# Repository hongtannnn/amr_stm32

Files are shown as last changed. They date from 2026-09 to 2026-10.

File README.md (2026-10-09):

# AMR Hardware & PCB Design (amr_stm32)



[]()

A low-level controller board and hardware system designed as the foundation for an Autonomous Mobile Robot (AMR). The project focuses on real-time task processing, sensor communication, and motor control in preparation for future integration with ROS 2, SLAM algorithms, and autonomous navigation.

## 📸 Board Preview

| 3D Render | Bare PCB (Unassembled) | Real Board (Assembled) |
| :---: | :---: | :---: |
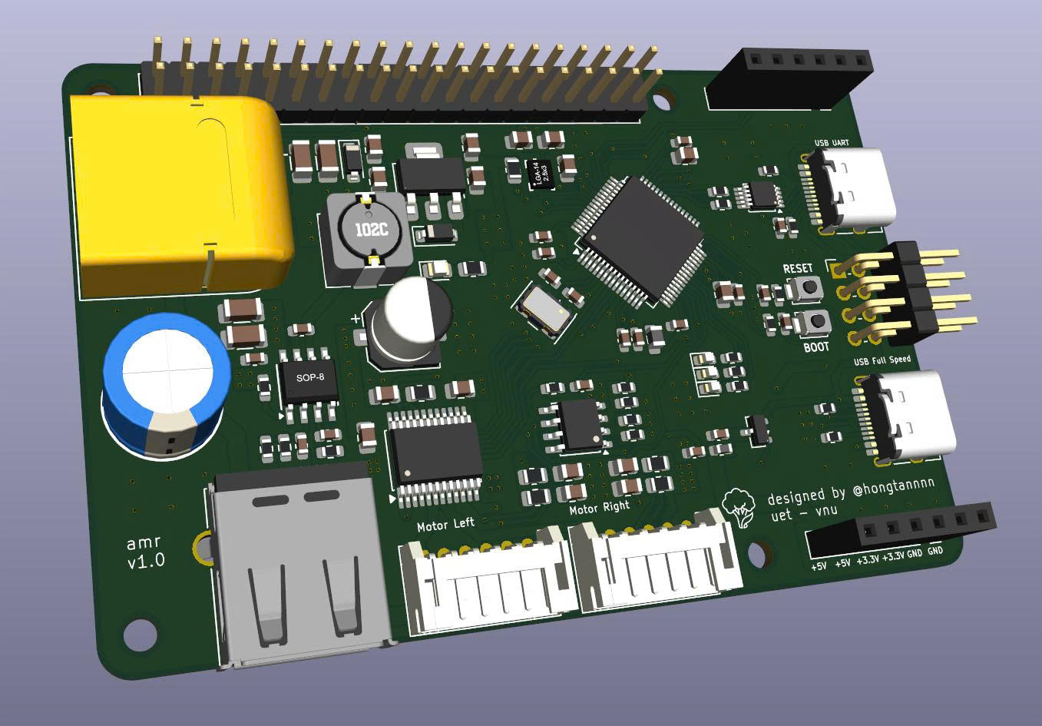
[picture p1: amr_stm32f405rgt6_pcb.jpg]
AMR STM32 3D Render
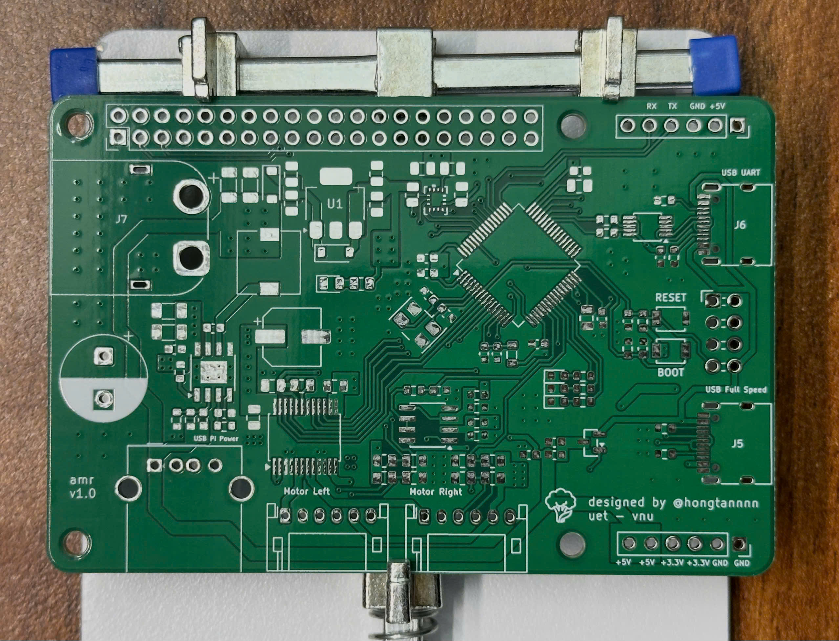
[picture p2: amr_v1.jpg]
AMR STM32 Bare PCB
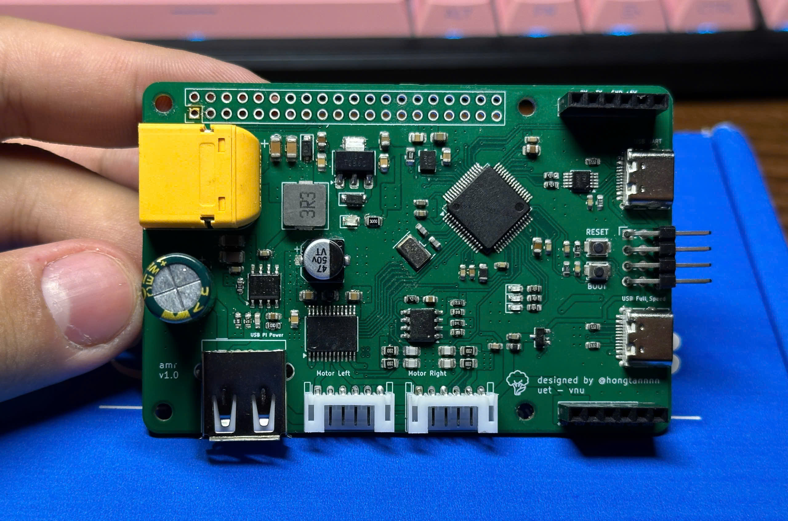
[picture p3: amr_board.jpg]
AMR STM32 Real Board
|  |  |  |
| *Completed PCB design featuring peripheral connectors, power supply block, and central microcontroller.* | *Newly fabricated AMR v1.0 bare board, showing silkscreen details and routing before component assembly.* | *Actual assembled PCB (AMR v1.0) with all components soldered and ready for testing.* |

## 🚀 Hardware Features

-   **Central Microcontroller (MCU):** Utilizes the **STM32F405RGT6** chip, providing powerful processing capabilities for PID algorithms and high-speed encoder reading.
-   **Industrial-grade Design:** 4-layer layout with dedicated GND and Power (VCC) planes, ensuring Signal Integrity and Electromagnetic Interference (EMI) reduction when operating in environments with electrical motors.

## 🛠 Tools & Software

-   **Hardware Design (EDA):** KiCad
-   **Embedded Programming:** STM32CubeIDE / STM32CubeMX
-   **Mechanical Design (CAD):** Autodesk Fusion 360

## 🎯 Future Roadmap

- [ ] Complete basic Firmware: Read encoders, control DC/BLDC motors via PID.
- [ ] Establish stable UART/I2C communication protocols between the STM32 and embedded computers (Raspberry Pi/Mini PC).
- [ ] Integrate the microcontroller package into the **ROS 2** network (using micro-ROS or rosserial).
- [ ] Deploy LiDAR and IMU sensors for mapping (SLAM) and navigation.

---
**Author:** Truong Hong Tan (@hongtannnn)  
*Student at the University of Engineering and Technology (UET) - Vietnam National University, Hanoi.*

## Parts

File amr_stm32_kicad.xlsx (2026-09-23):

Reference | Qty | Value | Footprint
C1,C2 | 2 | 2.2uF | Capacitor_SMD:C_0603_1608Metric
C9 | 1 | 10uF/16V | Capacitor_SMD:C_0805_2012Metric
C10,C11,C15,C17,C19,C20,C49 | 7 | 100nF/50V | Capacitor_SMD:C_0805_2012Metric
C12 | 1 | 22uF/10V | Capacitor_SMD:C_0805_2012Metric
C16 | 1 | 1uF/16V | Capacitor_SMD:C_0805_2012Metric
C18 | 1 | 10uF/25V | Capacitor_SMD:CP_Elec_6.3x7.7 | shopee
C21,C22,C23,C24 | 4 | 20pF/50V | Capacitor_SMD:C_0805_2012Metric
C25,C26,C27,C28,C29,C31,C36,C37,C39,C41,C44 | 9 | 100nF | Capacitor_SMD:C_0603_1608Metric
C30 | 1 | 1uF | Capacitor_SMD:C_0603_1608Metric
C32,C33 | 2 | 2.2uF | Capacitor_SMD:C_0805_2012Metric
C34,C35 | 2 | 22pF | Capacitor_SMD:C_0603_1608Metric
C38, C43 | 1 | 470nF | Capacitor_SMD:C_0603_1608Metric
C40,C47 | 2 | 10uF | Capacitor_SMD:C_1206_3216Metric
C42 | 1 | 5pF | Capacitor_SMD:C_0603_1608Metric
C45,C46 | 2 | 22uF | Capacitor_SMD:C_1206_3216Metric
C48 | 1 | 1000uF/35V | Capacitor_THT:CP_Radial_D10.0mm_P5.00mm
D1,D2 | 2 | D_Schottky 1A/40V | Diode_SMD:D_SOD-123
D3 | 1 | LED | LED_SMD:LED_0805_2012Metric
D5 | 1 | LED_RUN | LED_SMD:LED_0603_1608Metric
D6,D7 | 2 | LED_ERR | LED_SMD:LED_0603_1608Metric
FB1 | 1 | FerriteBead | Inductor_SMD:L_0805_2012Metric
FB2 | 1 | F120R | Inductor_SMD:L_0603_1608Metric
J1 | 1 | Header 2x20 | Connector_PinHeader_2.54mm:PinHeader_2x20_P2.54mm_Vertical
J2 | 1 | Motor_Left | Connector_JST:JST_PH_S6B-PH-K_1x06_P2.00mm_Horizontal
J3 | 1 | Motor_right | Connector_JST:JST_PH_S6B-PH-K_1x06_P2.00mm_Horizontal
J4 | 1 | ST_Link | Connector_PinHeader_2.54mm:PinHeader_2x04_P2.54mm_Horizontal
J5 | 1 | USB_FS_Interface | Connector_USB:USB_C_Receptacle_HRO_TYPE-C-31-M-12
J6 | 1 | USB_UART | Connector_USB:USB_C_Receptacle_HRO_TYPE-C-31-M-12
J7 | 1 | +12V_BAT | Connector_AMASS:AMASS_XT60PW-M_1x02_P7.20mm_Horizontal
J8 | 1 | USB_A_Pi | Connector_USB:USB_A_Molex_67643_Horizontal
J9 | 1 | UART | Connector_PinSocket_2.54mm:PinSocket_1x06_P2.54mm_Vertical
J10 | 1 | VCC | Connector_PinSocket_2.54mm:PinSocket_1x06_P2.54mm_Vertical
L2 | 1 | 3.3uH | Inductor_SMD:L_7.3x7.3_H4.5
Q1 | 1 | FDN304P | Package_TO_SOT_SMD:SOT-23
R3 | 1 | 300Ohm | Resistor_SMD:R_0805_2012Metric
R4,R5,R7,R8,R9,R10 | 6 | 10kOhm | Resistor_SMD:R_0805_2012Metric
R6,R11,R14,R27 | 4 | 10kOhm | Resistor_SMD:R_0603_1608Metric
R12,R13,R21,R22 | 4 | 5.1kOhm | Resistor_SMD:R_0603_1608Metric
R15 | 1 | 2kOhm | Resistor_SMD:R_0603_1608Metric
R16 | 1 | 9kOhm | Resistor_SMD:R_0603_1608Metric
R17 | 1 | 1kOhm | Resistor_SMD:R_0603_1608Metric
R18,R19,R20 | 3 | 470Ohm | Resistor_SMD:R_0603_1608Metric
R23,R24,R29 | 3 | 330 Ohm | Resistor_SMD:R_0603_1608Metric
R25 | 1 | 374kOhm | Resistor_SMD:R_0603_1608Metric
R26 | 1 | 49.9kOhm | Resistor_SMD:R_0603_1608Metric
R28 | 1 | 100kOhm | Resistor_SMD:R_0603_1608Metric
SW1 | 1 | SW_Reset | Button_Switch_SMD:SW_SPST_B3U-1000P
SW2 | 1 | SW_BOOT | Button_Switch_SMD:SW_SPST_B3U-1000P
U2 | 1 | ap2112k-3.3 | Package_TO_SOT_SMD:SOT-23-5
U3 | 1 | BMI323 | BMI323:BMI323_BOS-L
U4 | 1 | TB6612FNG | Package_SO:SSOP-24_5.3x8.2mm_P0.65mm
U5 | 1 | STM32F405RGTx | Package_QFP:LQFP-64_10x10mm_P0.5mm
U6 | 1 | LM358 | Package_SO:SOIC-8_3.9x4.9mm_P1.27mm
U7 | 1 | CH340E | Package_SO:MSOP-10_3x3mm_P0.5mm
U9 | 1 | TPS56528DDA | Package_SO:Texas_HSOP-8-1EP_3.9x4.9mm_P1.27mm_ThermalVias
Y2 | 1 | 8MHz | Crystal:Crystal_SMD_5032-4Pin_5.0x3.2mm

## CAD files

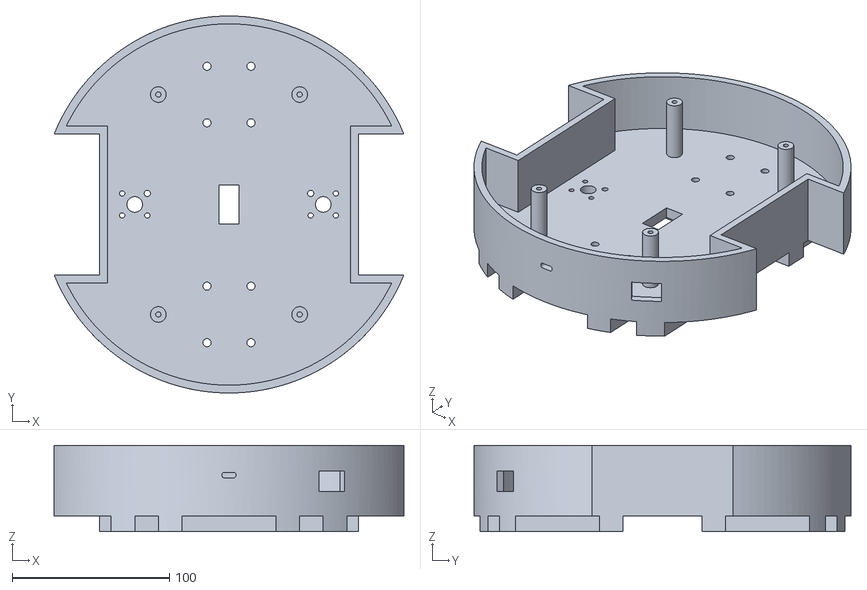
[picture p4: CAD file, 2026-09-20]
AMR_3D/Tang1.stl
222.5 x 240.0 x 55.0

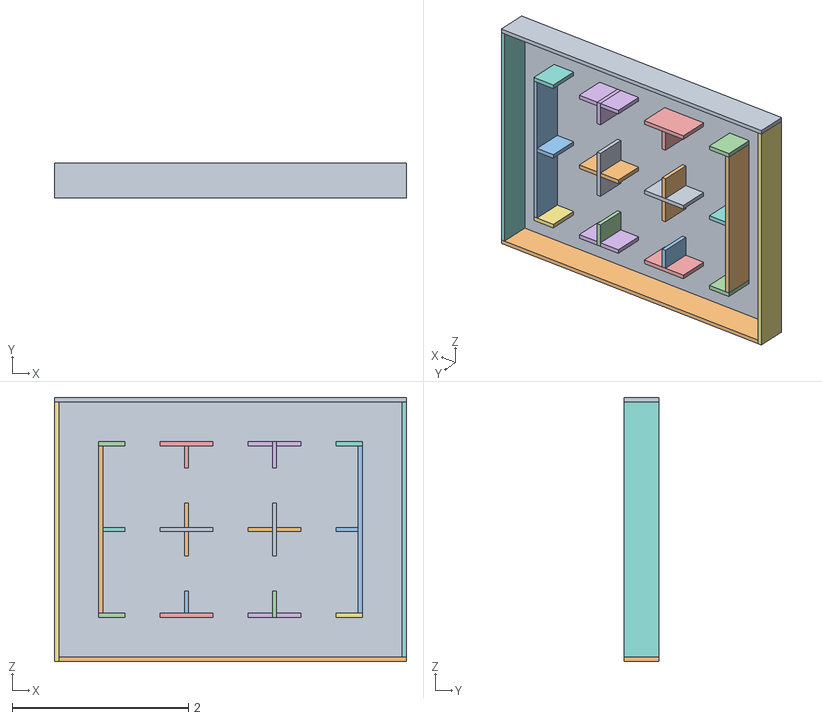
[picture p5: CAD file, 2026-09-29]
gazebo/maze_map.obj
4.00 x 0.4 x 3.00
Plane

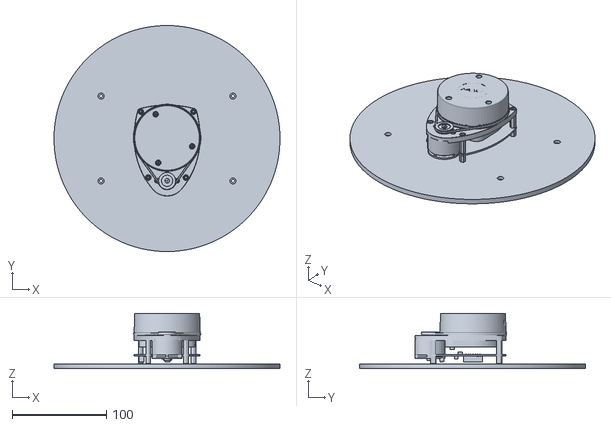
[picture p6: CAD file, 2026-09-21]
urdf/robot_assembly_description/meshes/Tang3_24cm_ComponentLidar_1_1.stl
240.0 x 240.0 x 58.7

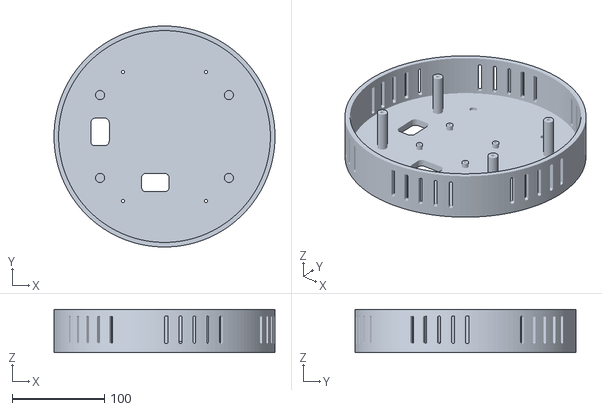
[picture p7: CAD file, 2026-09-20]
AMR_3D/Tang2.stl
240.0 x 240.0 x 47.0

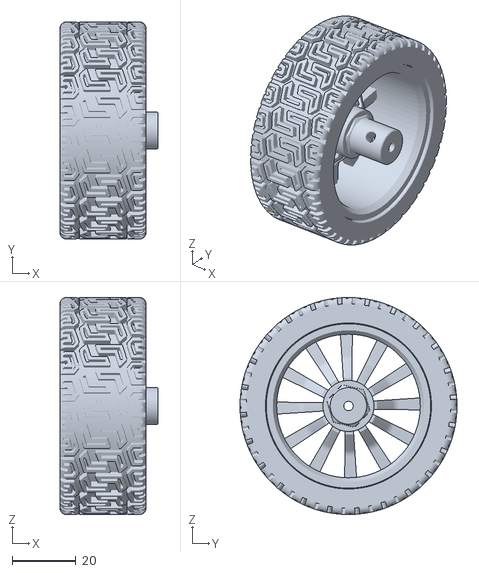
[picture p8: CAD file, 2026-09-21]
urdf/robot_assembly_description/meshes/left_wheel_1_1.stl
30.7 x 68.0 x 68.0

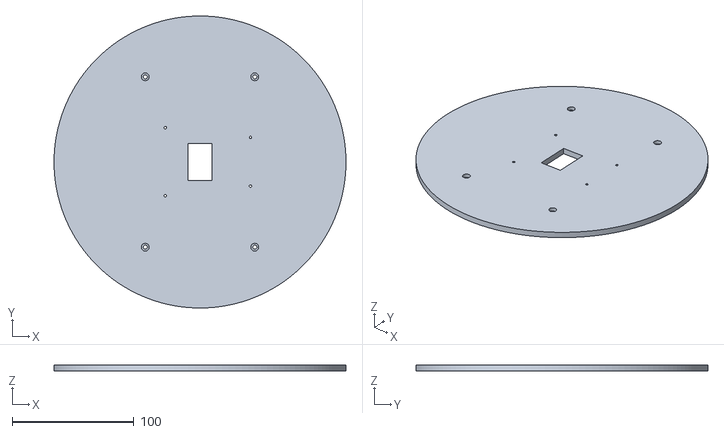
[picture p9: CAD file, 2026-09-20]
AMR_3D/Tang3.stl
240.0 x 240.0 x 5.00

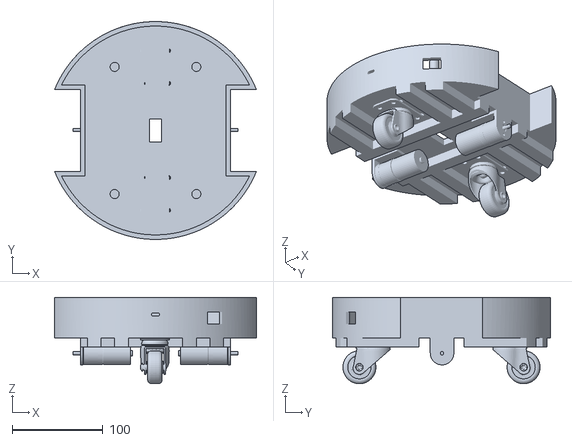
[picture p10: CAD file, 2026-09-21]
urdf/robot_assembly_description/meshes/base_link.stl
222.5 x 240.0 x 95.2

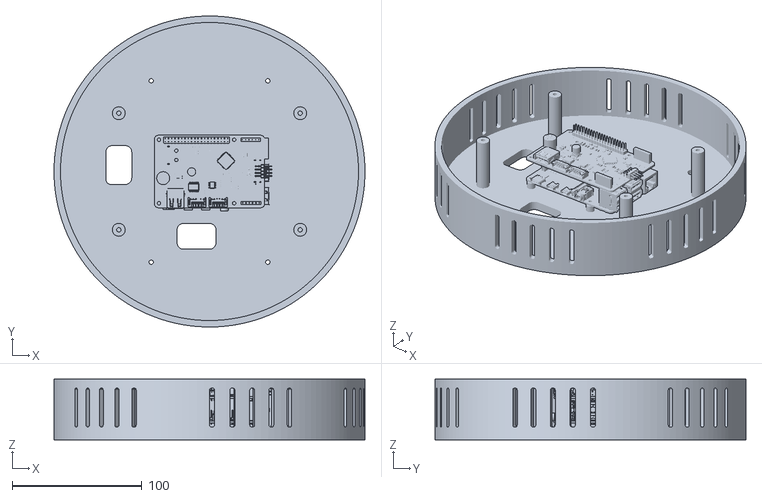
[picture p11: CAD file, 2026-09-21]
urdf/robot_assembly_description/meshes/Tang2_24cm_ComponentPi_1_1.stl
240.0 x 240.0 x 47.0

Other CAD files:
urdf/robot_assembly_description/meshes/right_wheel_1.stl
gazebo/maze_map.blend

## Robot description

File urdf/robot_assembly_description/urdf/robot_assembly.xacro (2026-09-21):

<?xml version="1.0" ?>
<robot name="robot_assembly" xmlns:xacro="http://www.ros.org/wiki/xacro">

<xacro:include filename="$(find robot_assembly_description)/urdf/materials.xacro" />
<xacro:include filename="$(find robot_assembly_description)/urdf/robot_assembly.trans" />
<xacro:include filename="$(find robot_assembly_description)/urdf/robot_assembly.gazebo" />
<link name="base_link">
  <inertial>
    <origin xyz="-0.0001801031310621884 0.00025924195261079174 0.003832242271524391" rpy="0 0 0"/>
    <mass value="5.341870907493194"/>
    <inertia ixx="0.025638" iyy="0.018383" izz="0.041044" ixy="-6.3e-05" iyz="-1.6e-05" ixz="3e-06"/>
  </inertial>
  <visual>
    <origin xyz="0 0 0" rpy="0 0 0"/>
    <geometry>
      <mesh filename="package://robot_assembly_description/meshes/base_link.stl" scale="0.001 0.001 0.001"/>
    </geometry>
    <material name="silver"/>
  </visual>
  <collision>
    <origin xyz="0 0 0" rpy="0 0 0"/>
    <geometry>
      <mesh filename="package://robot_assembly_description/meshes/base_link.stl" scale="0.001 0.001 0.001"/>
    </geometry>
  </collision>
</link>

<link name="left_wheel_1_1">
  <inertial>
    <origin xyz="-0.009252274703491131 -4.414402370967493e-06 -5.315775120334765e-06" rpy="0 0 0"/>
    <mass value="0.2717966197109235"/>
    <inertia ixx="0.0002" iyy="0.000119" izz="0.000119" ixy="-0.0" iyz="-0.0" ixz="-0.0"/>
  </inertial>
  <visual>
    <origin xyz="0.090987 -0.000611 0.016569" rpy="0 0 0"/>
    <geometry>
      <mesh filename="package://robot_assembly_description/meshes/left_wheel_1_1.stl" scale="0.001 0.001 0.001"/>
    </geometry>
    <material name="silver"/>
  </visual>
  <collision>
    <origin xyz="0.090987 -0.000611 0.016569" rpy="0 0 0"/>
    <geometry>
      <mesh filename="package://robot_assembly_description/meshes/left_wheel_1_1.stl" scale="0.001 0.001 0.001"/>
    </geometry>
  </collision>
</link>

<link name="right_wheel_1">
  <inertial>
    <origin xyz="0.009252355095506246 -6.634310137020602e-06 -2.4158363846199515e-07" rpy="0 0 0"/>
    <mass value="0.2717966197108583"/>
    <inertia ixx="0.0002" iyy="0.000119" izz="0.000119" ixy="0.0" iyz="-0.0" ixz="0.0"/>
  </inertial>
  <visual>
    <origin xyz="-0.090987 -0.000611 0.016569" rpy="0 0 0"/>
    <geometry>
      <mesh filename="package://robot_assembly_description/meshes/right_wheel_1.stl" scale="0.001 0.001 0.001"/>
    </geometry>
    <material name="silver"/>
  </visual>
  <collision>
    <origin xyz="-0.090987 -0.000611 0.016569" rpy="0 0 0"/>
    <geometry>
      <mesh filename="package://robot_assembly_description/meshes/right_wheel_1.stl" scale="0.001 0.001 0.001"/>
    </geometry>
  </collision>
</link>

<link name="Tang2_24cm_ComponentPi_1_1">
  <inertial>
    <origin xyz="0.0011619472588145366 0.00037962234624636104 0.04981801224075864" rpy="0 0 0"/>
    <mass value="3.7734661537037937"/>
    <inertia ixx="0.016801" iyy="0.01713" izz="0.032625" ixy="3e-06" iyz="1.4e-05" ixz="4e-06"/>
  </inertial>
  <visual>
    <origin xyz="0.0 -0.0 -0.007" rpy="0 0 0"/>
    <geometry>
      <mesh filename="package://robot_assembly_description/meshes/Tang2_24cm_ComponentPi_1_1.stl" scale="0.001 0.001 0.001"/>
    </geometry>
    <material name="silver"/>
  </visual>
  <collision>
    <origin xyz="0.0 -0.0 -0.007" rpy="0 0 0"/>
    <geometry>
      <mesh filename="package://robot_assembly_description/meshes/Tang2_24cm_ComponentPi_1_1.stl" scale="0.001 0.001 0.001"/>
    </geometry>
  </collision>
</link>

<link name="Tang3_24cm_ComponentLidar_1_1">
  <inertial>
    <origin xyz="-0.0002176504381086913 -0.0033925161264463212 0.09435239830255189" rpy="0 0 0"/>
    <mass value="2.3189387029545405"/>
    <inertia ixx="0.007248" iyy="0.006946" izz="0.013375" ixy="3e-06" iyz="8.5e-05" ixz="8e-06"/>
  </inertial>
  <visual>
    <origin xyz="0.0 -0.0 -0.007" rpy="0 0 0"/>
    <geometry>
      <mesh filename="package://robot_assembly_description/meshes/Tang3_24cm_ComponentLidar_1_1.stl" scale="0.001 0.001 0.001"/>
    </geometry>
    <material name="silver"/>
  </visual>
  <collision>
    <origin xyz="0.0 -0.0 -0.007" rpy="0 0 0"/>
    <geometry>
      <mesh filename="package://robot_assembly_description/meshes/Tang3_24cm_ComponentLidar_1_1.stl" scale="0.001 0.001 0.001"/>
    </geometry>
  </collision>
</link>

<joint name="Revolute 9" type="continuous">
  <origin xyz="-0.090987 0.000611 -0.016569" rpy="0 0 0"/>
  <parent link="base_link"/>
  <child link="left_wheel_1_1"/>
  <axis xyz="1.0 -0.0 -0.0"/>
</joint>

<joint name="Revolute 10" type="continuous">
  <origin xyz="0.090987 0.000611 -0.016569" rpy="0 0 0"/>
  <parent link="base_link"/>
  <child link="right_wheel_1"/>
  <axis xyz="1.0 0.0 0.0"/>
</joint>

<joint name="Rigid 11" type="fixed">
  <origin xyz="0.0 0.0 0.007" rpy="0 0 0"/>
  <parent link="base_link"/>
  <child link="Tang2_24cm_ComponentPi_1_1"/>
</joint>

<joint name="Rigid 12" type="fixed">
  <origin xyz="0.0 0.0 0.007" rpy="0 0 0"/>
  <parent link="base_link"/>
  <child link="Tang3_24cm_ComponentLidar_1_1"/>
</joint>

</robot>

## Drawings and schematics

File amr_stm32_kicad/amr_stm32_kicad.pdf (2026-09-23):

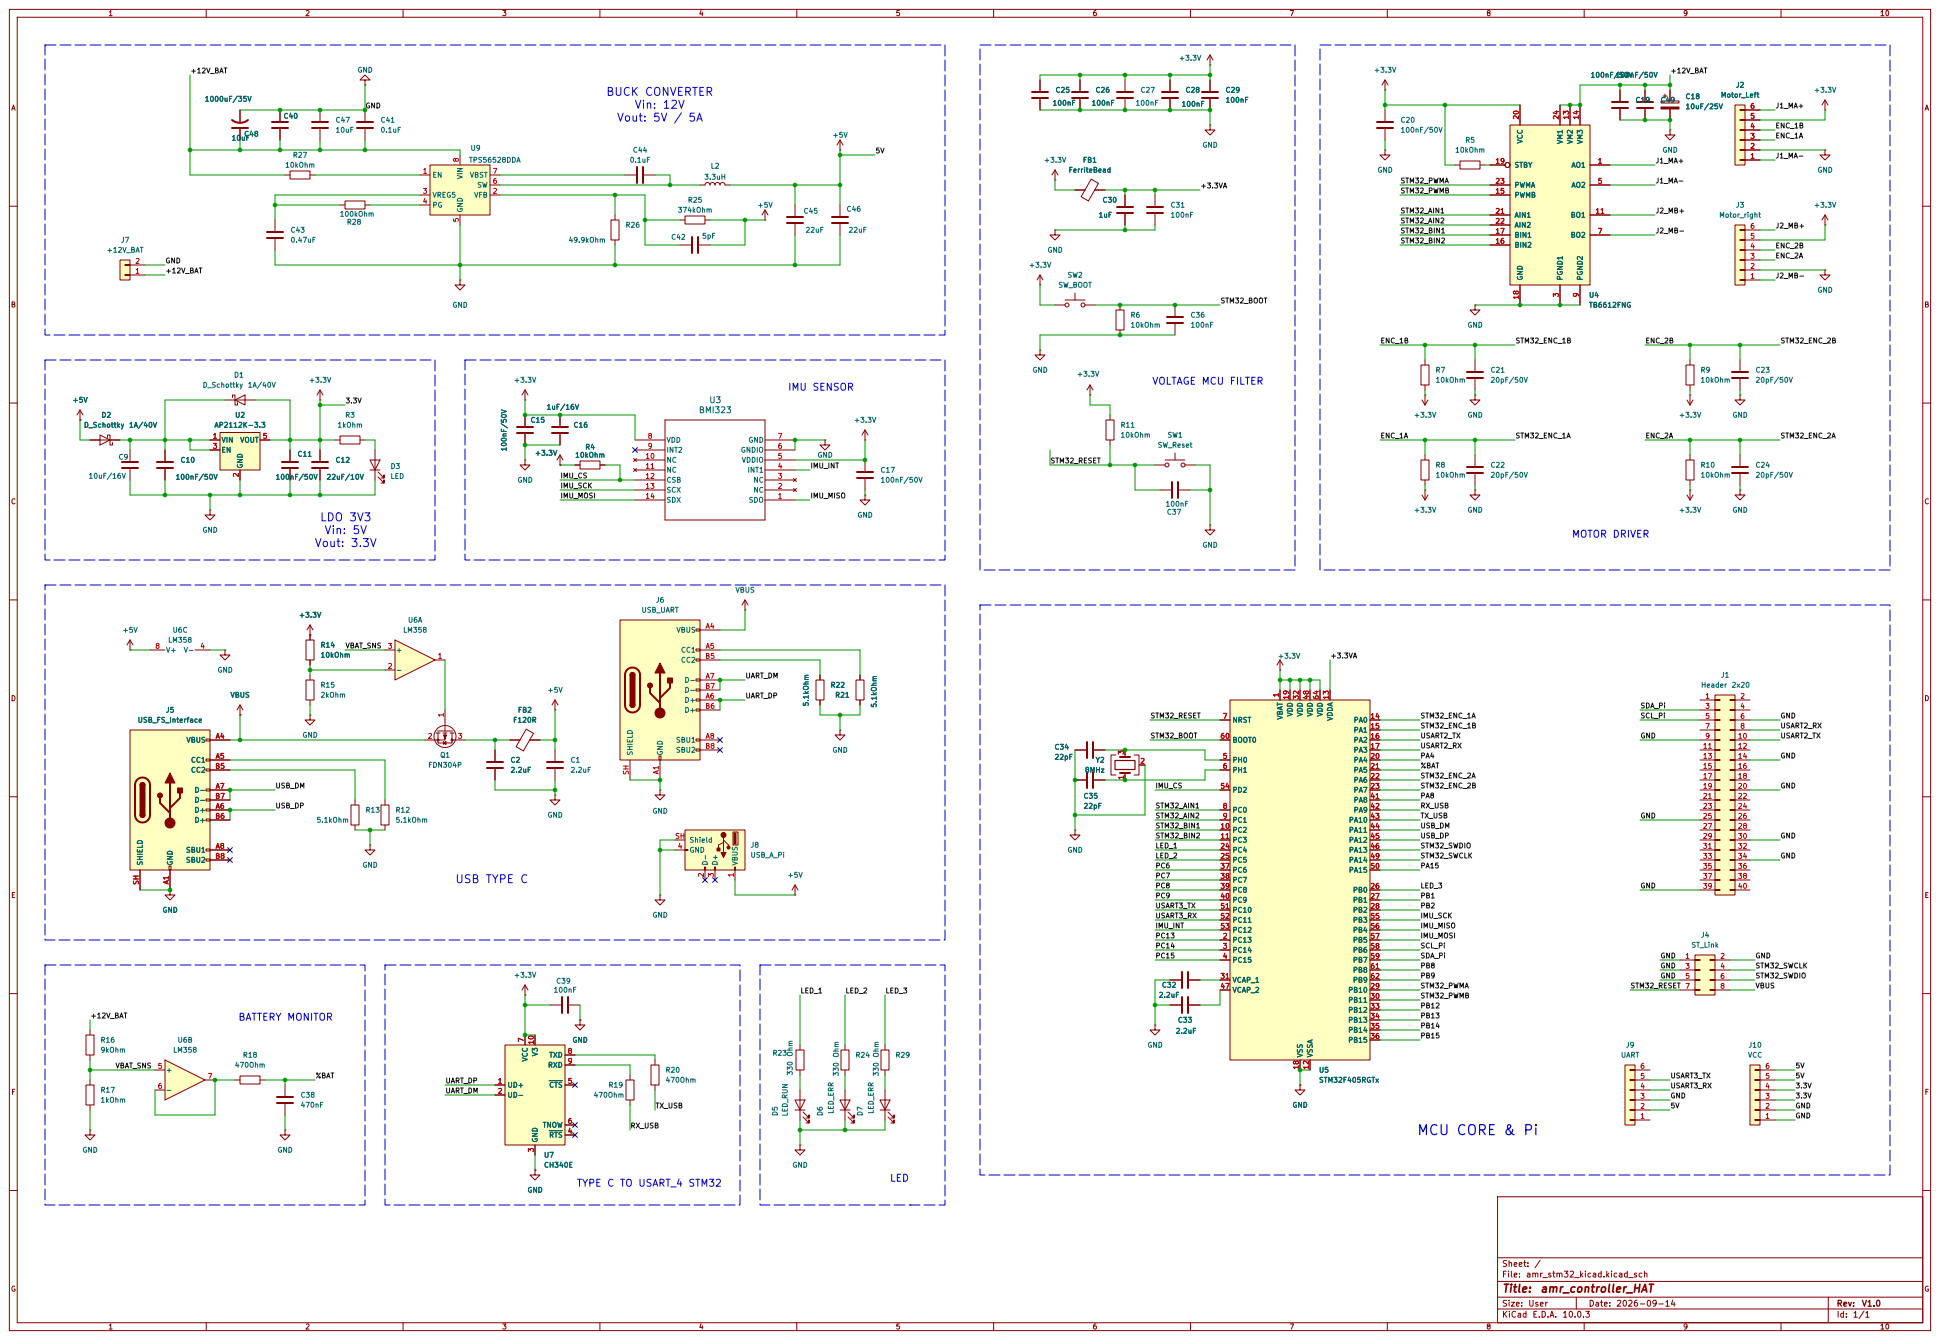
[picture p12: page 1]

Size: User | Rev: V1.0
KiCad E.D.A. 10.0.3 | Id: 1/1

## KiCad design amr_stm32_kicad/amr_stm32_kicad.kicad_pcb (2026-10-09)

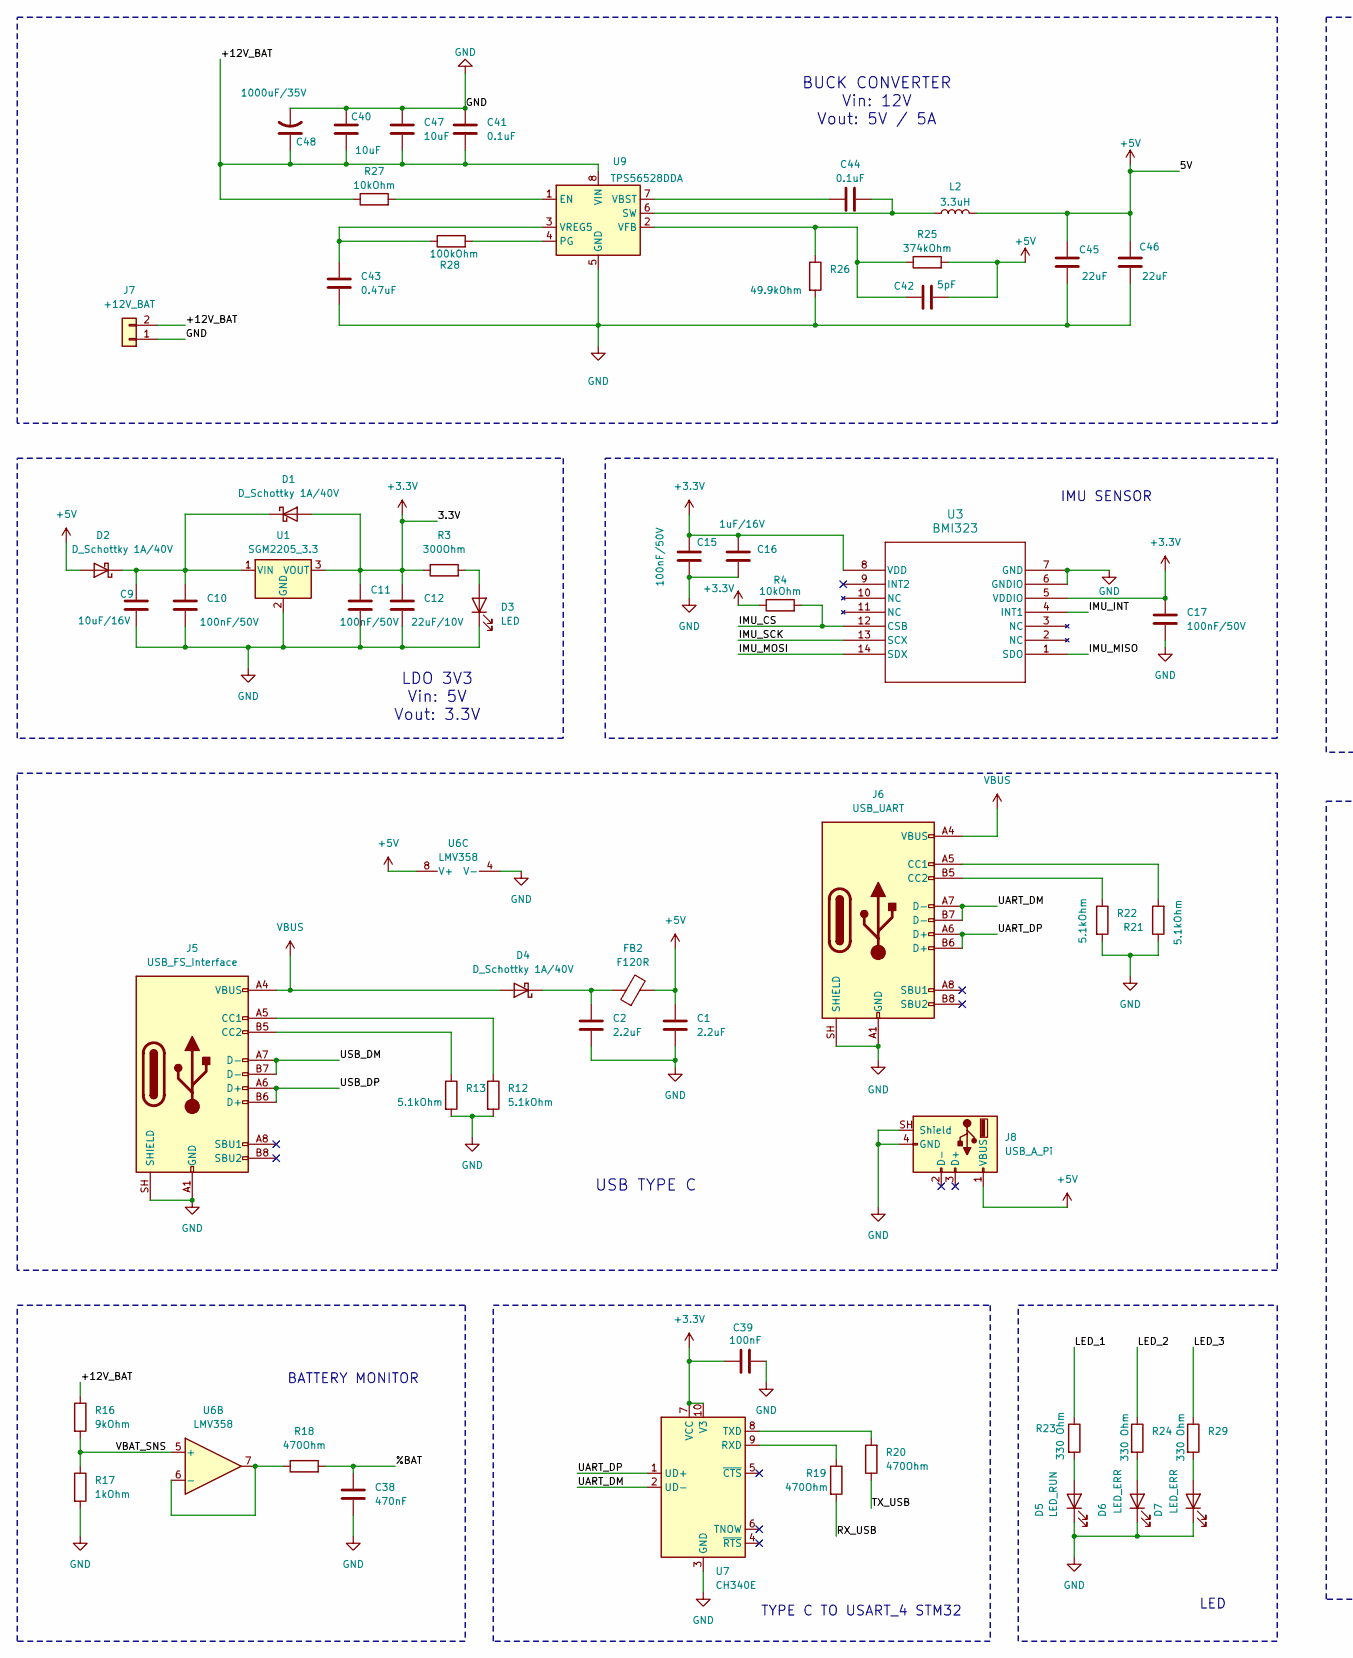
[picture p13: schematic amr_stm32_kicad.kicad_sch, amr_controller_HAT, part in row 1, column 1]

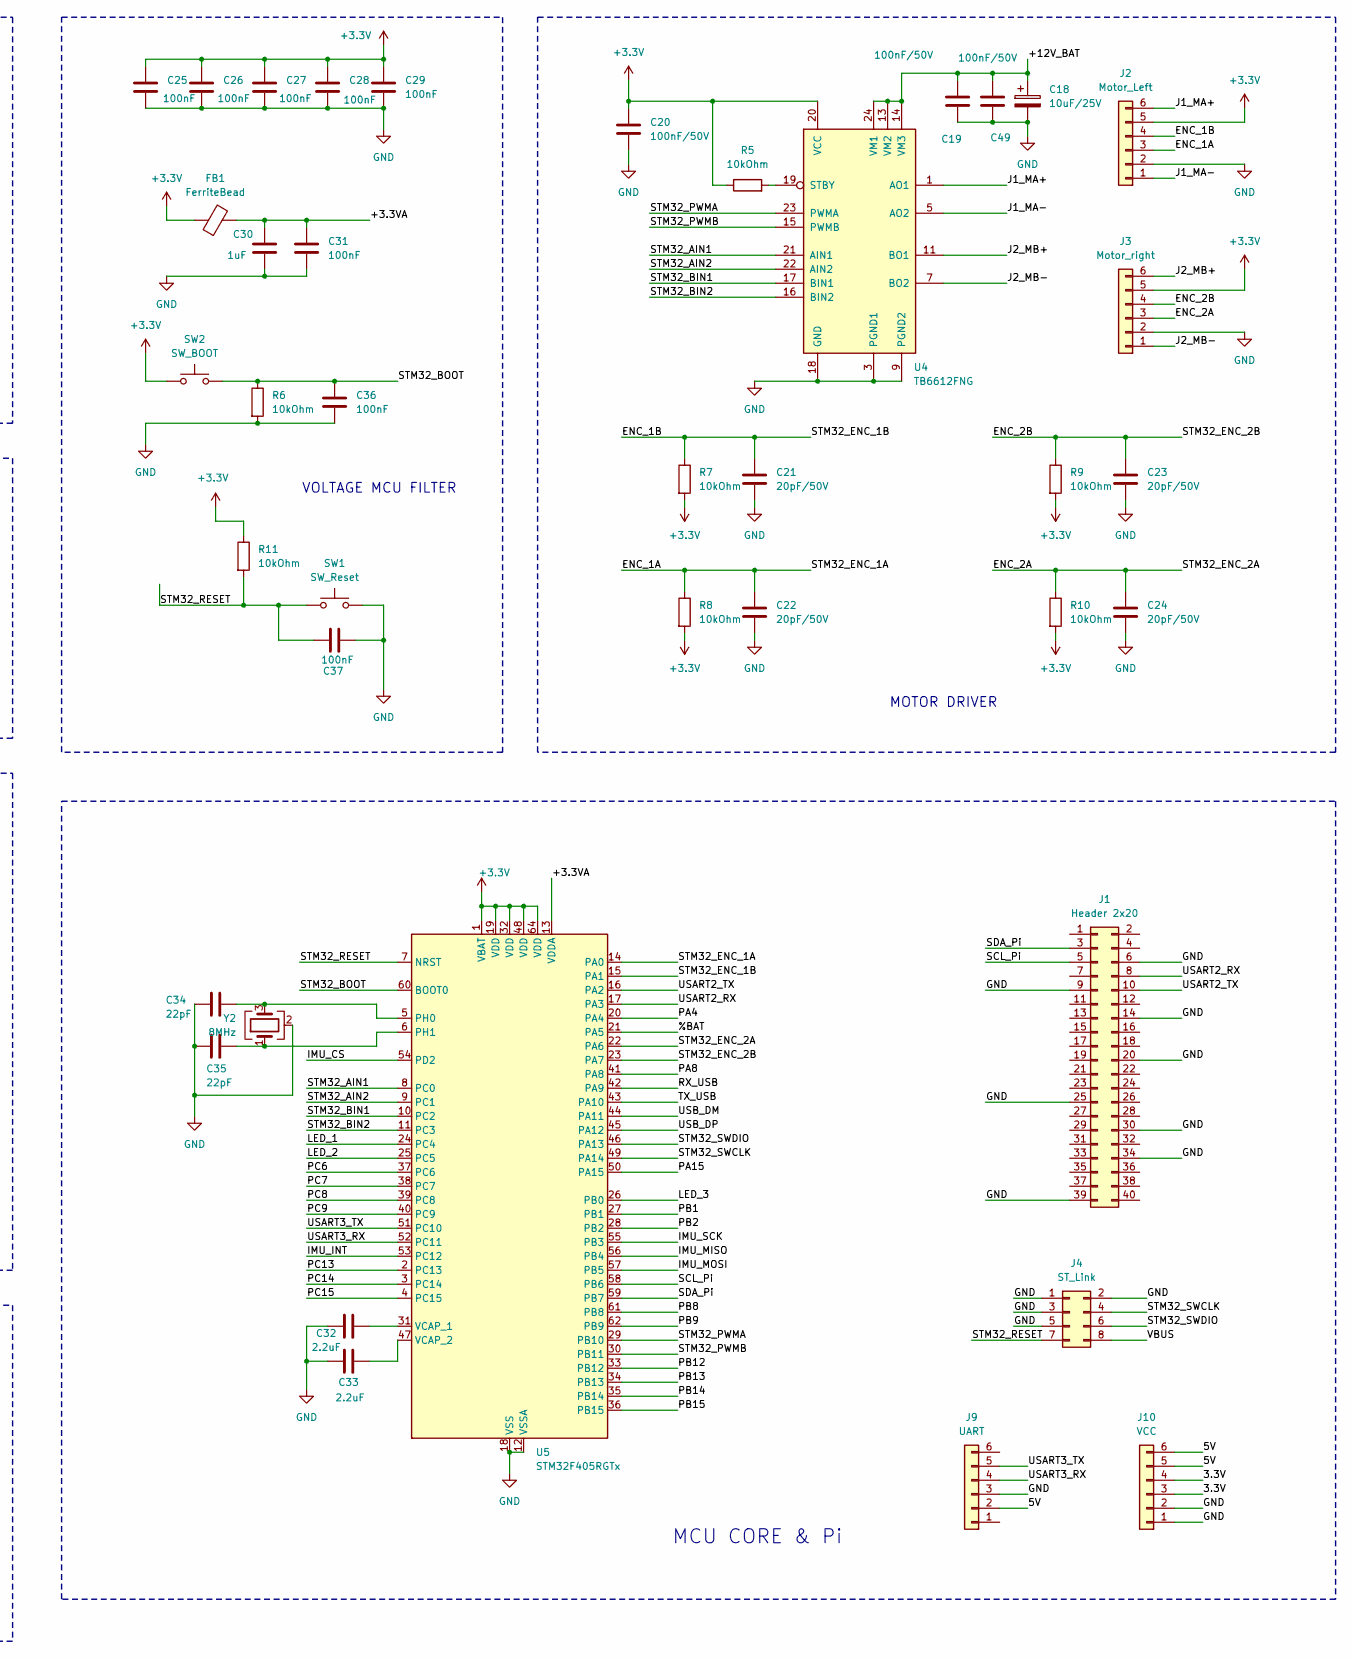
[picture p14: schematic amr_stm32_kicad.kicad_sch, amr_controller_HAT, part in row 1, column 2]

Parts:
C1, C2: 2.2uF; C_0603_1608Metric
C9: 10uF/16V; C_0805_2012Metric
C10, C11, C15, C17, C19, C20, C49: 100nF/50V; C_0805_2012Metric
C12: 22uF/10V; C_0805_2012Metric
C16: 1uF/16V; C_0805_2012Metric
C18: 10uF/25V; CP_Elec_6.3x7.7
C21, C22, C23, C24: 20pF/50V; C_0805_2012Metric
C25, C26, C27, C28, C29, C31, C36, C37, C39: 100nF; C_0603_1608Metric
C30: 1uF; C_0603_1608Metric
C32, C33: 2.2uF; C_0805_2012Metric
C34, C35: 22pF; C_0603_1608Metric
C38: 470nF; C_0603_1608Metric
C40, C47: 10uF; C_1206_3216Metric
C41, C44: 0.1uF; C_0603_1608Metric
C42: 5pF; C_0603_1608Metric
C43: 0.47uF; C_0603_1608Metric
C45, C46: 22uF; C_1206_3216Metric
C48: 1000uF/35V; CP_Radial_D10.0mm_P5.00mm
D1, D2, D4: D_Schottky 1A/40V; D_SOD-123
D3: LED; LED_0805_2012Metric
D5: LED_RUN; LED_0603_1608Metric
D6, D7: LED_ERR; LED_0603_1608Metric
FB1: FerriteBead; L_0805_2012Metric
FB2: F120R; L_0603_1608Metric
J1: Header 2x20; PinHeader_2x20_P2.54mm_Vertical
J2: Motor_Left; JST_PH_S6B-PH-K_1x06_P2.00mm_Horizontal
J3: Motor_right; JST_PH_S6B-PH-K_1x06_P2.00mm_Horizontal
J4: ST_Link; PinHeader_2x04_P2.54mm_Horizontal
J5: USB_FS_Interface; USB_C_Receptacle_HRO_TYPE-C-31-M-12
J6: USB_UART; USB_C_Receptacle_HRO_TYPE-C-31-M-12
J7: +12V_BAT; AMASS_XT60PW-M_1x02_P7.20mm_Horizontal
J8: USB_A_Pi; USB_A_Molex_67643_Horizontal
J9: UART; PinSocket_1x06_P2.54mm_Vertical
J10: VCC; PinSocket_1x06_P2.54mm_Vertical
L2: 3.3uH; L_7.3x7.3_H4.5
R3: 300Ohm; R_0805_2012Metric
R4, R5, R7, R8, R9, R10: 10kOhm; R_0805_2012Metric
R6, R11, R27: 10kOhm; R_0603_1608Metric
R12, R13, R21, R22: 5.1kOhm; R_0603_1608Metric
R16: 9kOhm; R_0603_1608Metric
R17: 1kOhm; R_0603_1608Metric
R18, R19, R20: 470Ohm; R_0603_1608Metric
R23, R24, R29: 330 Ohm; R_0603_1608Metric
R25: 374kOhm; R_0603_1608Metric
R26: 49.9kOhm; R_0603_1608Metric
R28: 100kOhm; R_0603_1608Metric
SW1: SW_Reset; SW_SPST_B3U-1000P
SW2: SW_BOOT; SW_SPST_B3U-1000P
U1: SGM2205_3.3; SOT-223-3_TabPin2
U3: BMI323; BMI323_BOS-L
U4: TB6612FNG; SSOP-24_5.3x8.2mm_P0.65mm
U5: STM32F405RGTx; LQFP-64_10x10mm_P0.5mm
U6: LMV358; SOIC-8_3.9x4.9mm_P1.27mm
U7: CH340E; MSOP-10_3x3mm_P0.5mm
U9: TPS56528DDA; Texas_HSOP-8-1EP_3.9x4.9mm_P1.27mm_ThermalVias
Y2: 8MHz; Crystal_SMD_5032-4Pin_5.0x3.2mm

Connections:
+3.3V: C11.1, C12.1, C15.1, C16.1, C17.1, C20.1, C25.1, C26.1, C27.1, C28.1, C29.1, C39.1, D1.2 (A), FB1.1, J2.5, J3.5, J10.3, J10.4, R3.1, R4.1, R5.1, R7.2, R8.2, R9.2, R10.2, R11.1, SW2.1, U1.3 (VOUT), U3.5 (VDDIO), U3.8 (VDD), U4.20 (VCC), U5.1 (VBAT), U5.19 (VDD), U5.32 (VDD), U5.48 (VDD), U5.64 (VDD), U7.7 (VCC), U7.10 (V3)
+5V: C1.1, C42.1, C45.1, C46.1, D2.2 (A), FB2.2, J8.1 (VBUS), J9.2, J10.5, J10.6, L2.1, R25.2, U6.8 (V+)
/%BAT: C38.1, R18.2, U5.21 (PA5)
/+3.3VA: C30.1, C31.1, FB1.2, U5.13 (VDDA)
/+12V_BAT: C18.1, C19.1, C40.2, C41.2, C47.2, C48.1, C49.1, J7.2, R16.1, R27.1, U4.13 (VM2), U4.14 (VM3), U4.24 (VM1), U9.8 (VIN)
/ENC_1A: C22.1, J2.3, R8.1, U5.14 (PA0)
/ENC_1B: C21.1, J2.4, R7.1, U5.15 (PA1)
/ENC_2A: C24.1, J3.3, R10.1, U5.22 (PA6)
/ENC_2B: C23.1, J3.4, R9.1, U5.23 (PA7)
/IMU_CS: R4.2, U3.12 (CSB), U5.54 (PD2)
/IMU_INT: U3.4 (INT1), U5.53 (PC12)
/IMU_MISO: U3.1 (SDO), U5.56 (PB4)
/IMU_MOSI: U3.14 (SDX), U5.57 (PB5)
/IMU_SCK: U3.13 (SCX), U5.55 (PB3)
/J1_MA+: J2.6, U4.1 (AO1), U4.2 (AO1)
/J1_MA-: J2.1, U4.5 (AO2), U4.6 (AO2)
/J2_MB+: J3.6, U4.11 (BO1), U4.12 (BO1)
/J2_MB-: J3.1, U4.7 (BO2), U4.8 (BO2)
/LED_1: R23.1, U5.24 (PC4)
/LED_2: R24.1, U5.25 (PC5)
/LED_3: R29.1, U5.26 (PB0)
/PA4: U5.20 (PA4)
/PA8: U5.41 (PA8)
/PA15: U5.50 (PA15)
/PB1: U5.27 (PB1)
/PB2: U5.28 (PB2)
/PB8: U5.61 (PB8)
/PB9: U5.62 (PB9)
/PB12: U5.33 (PB12)
/PB13: U5.34 (PB13)
/PB14: U5.35 (PB14)
/PB15: U5.36 (PB15)
/PC6: U5.37 (PC6)
/PC7: U5.38 (PC7)
/PC8: U5.39 (PC8)
/PC9: U5.40 (PC9)
/PC13: U5.2 (PC13)
/PC14: U5.3 (PC14)
/PC15: U5.4 (PC15)
/RX_USB: R19.2, U5.42 (PA9)
/SCL_Pi: J1.5, U5.58 (PB6)
/SDA_Pi: J1.3, U5.59 (PB7)
/STM32_AIN1: U4.21 (AIN1), U5.8 (PC0)
/STM32_AIN2: U4.22 (AIN2), U5.9 (PC1)
/STM32_BIN1: U4.17 (BIN1), U5.10 (PC2)
/STM32_BIN2: U4.16 (BIN2), U5.11 (PC3)
/STM32_BOOT: C36.1, R6.1, SW2.2, U5.60 (BOOT0)
/STM32_PWMA: U4.23 (PWMA), U5.29 (PB10)
/STM32_PWMB: U4.15 (PWMB), U5.30 (PB11)
/STM32_RESET: C37.1, J4.7, R11.2, SW1.1, U5.7 (NRST)
/STM32_SWCLK: J4.4, U5.49 (PA14)
/STM32_SWDIO: J4.6, U5.46 (PA13)
/TX_USB: R20.1, U5.43 (PA10)
/UART_DM: J6.A7 (D-), J6.B7 (D-), U7.2 (UD-)
/UART_DP: J6.A6 (D+), J6.B6 (D+), U7.1 (UD+)
/USART2_RX: J1.8, U5.17 (PA3)
/USART2_TX: J1.10, U5.16 (PA2)
/USART3_RX: J9.4, U5.52 (PC11)
/USART3_TX: J9.5, U5.51 (PC10)
/USB_DM: J5.A7 (D-), J5.B7 (D-), U5.44 (PA11)
/USB_DP: J5.A6 (D+), J5.B6 (D+), U5.45 (PA12)
/VBAT_SNS: R16.2, R17.1, U6.5 (+)
GND: C1.2, C2.2, C9.2, C10.2, C11.2, C12.2, C15.2, C16.2, C17.2, C18.2, C19.2, C20.2, C21.2, C22.2, C23.2, C24.2, C25.2, C26.2, C27.2, C28.2, C29.2, C30.2, C31.2, C32.1, C33.1, C34.2, C35.2, C36.2, C37.2, C38.2, C39.2, C40.1, C41.1, C43.2, C45.2, C46.2, C47.1, C48.2, C49.2, D3.1 (K), D5.1 (K), D6.1 (K), D7.1 (K), J1.6, J1.9, J1.14, J1.20, J1.25, J1.30, J1.34, J1.39, J2.2, J3.2, J4.1, J4.2, J4.3, J4.5, J5.A1 (GND), J5.A12 (GND), J5.B1 (GND), J5.B12 (GND), J5.SH (SHIELD), J6.A1 (GND), J6.A12 (GND), J6.B1 (GND), J6.B12 (GND), J6.SH (SHIELD), J7.1, J8.4 (GND), J8.SH (Shield), J9.3, J10.1, J10.2, R6.2, R12.2, R13.2, R17.2, R21.1, R22.2, R26.2, SW1.2, U1.2 (GND), U3.6 (GNDIO), U3.7 (GND), U4.3 (PGND1), U4.4 (PGND1), U4.9 (PGND2), U4.10 (PGND2), U4.18 (GND), U5.12 (VSSA), U5.18 (VSS), U5.63 (VSS), U6.4 (V-), U7.3 (GND), U9.5 (GND), U9.9 (GND), Y2.2 (G), Y2.4 (G)
unnamed: C9.1, C10.1, D1.1 (K), D2.1 (K), U1.1 (VIN)
unnamed: D3.2 (A), R3.2
unnamed: C2.1, D4.1 (K), FB2.1
unnamed: D5.2 (A), R23.2
unnamed: D6.2 (A), R24.2
unnamed: D7.2 (A), R29.2
unnamed: J5.A5 (CC1), R12.1
unnamed: J5.B5 (CC2), R13.1
unnamed: J6.A5 (CC1), R21.2
unnamed: J6.B5 (CC2), R22.1
unnamed: R5.2, U4.19 (STBY)
unnamed: C34.1, U5.5 (PH0), Y2.3
unnamed: C35.1, U5.6 (PH1), Y2.1
unnamed: C32.2, U5.31 (VCAP_1)
unnamed: C33.2, U5.47 (VCAP_2)
unnamed: R18.1, U6.6 (-), U6.7
unnamed: R19.1, U7.9 (RXD)
unnamed: R20.2, U7.8 (TXD)
unnamed: R27.2, U9.1 (EN)
unnamed: R28.2, U9.4 (PG)
unnamed: C44.2, L2.2, U9.6 (SW)
unnamed: C44.1, U9.7 (VBST)
unnamed: C42.2, R25.1, R26.1, U9.2 (VFB)
unnamed: C43.1, R28.1, U9.3 (VREG5)
VBUS: D4.2 (A), J4.8, J5.A4 (VBUS), J5.A9 (VBUS), J5.B4 (VBUS), J5.B9 (VBUS), J6.A4 (VBUS), J6.A9 (VBUS), J6.B4 (VBUS), J6.B9 (VBUS)

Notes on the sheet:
BUCK CONVERTER Vin: 12V Vout: 5V / 5A
IMU SENSOR
MCU CORE & Pi
TYPE C TO USART_4 STM32
BATTERY MONITOR
USB TYPE C
LED
VOLTAGE MCU FILTER
MOTOR DRIVER
LDO 3V3 Vin: 5V Vout: 3.3V

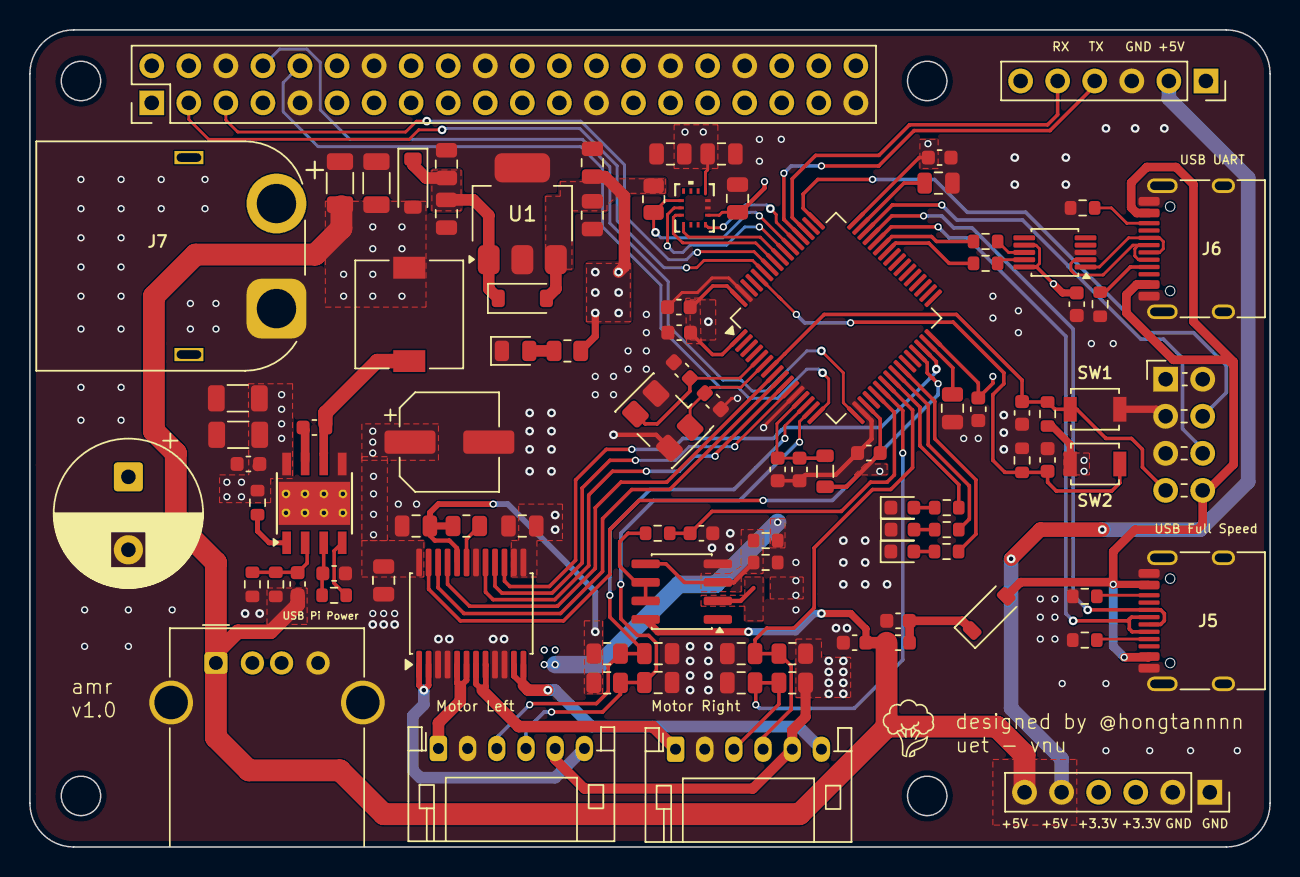
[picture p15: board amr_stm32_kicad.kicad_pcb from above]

Board: 4 copper layers, 85.0 x 56.0 mm, 96 parts (0 on the bottom side), 70 nets.

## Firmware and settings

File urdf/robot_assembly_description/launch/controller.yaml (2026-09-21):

robot_assembly_controller:
  # Publish all joint states -----------------------------------
  joint_state_controller:
    type: joint_state_controller/JointStateController
    publish_rate: 50

  # Position Controllers --------------------------------------
  Revolute 9_position_controller:
    type: effort_controllers/JointPositionController
    joint: Revolute 9
    pid: {p: 100.0, i: 0.01, d: 10.0}
  Revolute 10_position_controller:
    type: effort_controllers/JointPositionController
    joint: Revolute 10
    pid: {p: 100.0, i: 0.01, d: 10.0}

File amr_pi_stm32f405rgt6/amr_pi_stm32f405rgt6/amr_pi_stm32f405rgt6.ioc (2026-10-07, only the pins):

Mcu.UserName=STM32F405RGTx
PA0-WKUP.Signal=S_TIM5_CH1
PA1.Signal=S_TIM5_CH2
PA10.Signal=USART1_RX
PA11.Signal=USB_OTG_FS_DM
PA12.Signal=USB_OTG_FS_DP
PA13.Signal=SYS_JTMS-SWDIO
PA14.Signal=SYS_JTCK-SWCLK
PA2.Signal=USART2_TX
PA3.Signal=USART2_RX
PA5.Signal=ADCx_IN5
PA6.Signal=S_TIM3_CH1
PA7.Signal=S_TIM3_CH2
PA9.Signal=USART1_TX
PB0.Signal=GPIO_Output
PB10.Signal=S_TIM2_CH3
PB11.Signal=S_TIM2_CH4
PB3.Signal=SPI1_SCK
PB4.Signal=SPI1_MISO
PB5.Signal=SPI1_MOSI
PB6.Signal=I2C1_SCL
PB7.Signal=I2C1_SDA
PC0.Signal=GPIO_Output
PC1.Signal=GPIO_Output
PC10.Signal=USART3_TX
PC11.Signal=USART3_RX
PC12.Signal=GPXTI12
PC2.Signal=GPIO_Output
PC3.Signal=GPIO_Output
PC4.Signal=GPIO_Output
PC5.Signal=GPIO_Output
PD2.Signal=GPIO_Output
PH0-OSC_IN.Signal=RCC_OSC_IN
PH1-OSC_OUT.Signal=RCC_OSC_OUT

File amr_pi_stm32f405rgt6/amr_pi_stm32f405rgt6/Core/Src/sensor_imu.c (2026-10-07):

#include "sensor_imu.h"
#include "spi.h"   // Thư viện SPI do CubeMX sinh ra (chứa hspi1)
#include "main.h"  // Chứa định nghĩa các chân GPIO

// =====================================================================
// ĐỊNH NGHĨA SPI & THANH GHI BMI323
// =====================================================================
#define BMI323_REG_CHIP_ID  0x00
#define BMI323_REG_ACC_CONF 0x20
#define BMI323_REG_GYR_CONF 0x21
#define BMI323_REG_ACC_X    0x03

// Chân CS (Chip Select)
#define BMI323_CS_PORT      GPIOD
#define BMI323_CS_PIN       GPIO_PIN_2

extern SPI_HandleTypeDef hspi1;

// =====================================================================
// BIẾN TOÀN CỤC
// =====================================================================
uint8_t bmi323_chip_id = 0;

volatile int16_t acc_raw[3] = {0, 0, 0};
volatile int16_t gyr_raw[3] = {0, 0, 0};

volatile float ax_g = 0.0f, ay_g = 0.0f, az_g = 0.0f;
volatile float gx_dps = 0.0f, gy_dps = 0.0f, gz_dps = 0.0f;

// =====================================================================
// HÀM TRỢ GIÚP GIAO TIẾP SPI CHO BMI323
// =====================================================================
static void BMI323_SPI_Write(uint8_t reg, uint8_t *data, uint16_t len) {
    uint8_t tx_reg = reg & 0x7F; // Bit 7 = 0 để Ghi

    HAL_GPIO_WritePin(BMI323_CS_PORT, BMI323_CS_PIN, GPIO_PIN_RESET);
    HAL_SPI_Transmit(&hspi1, &tx_reg, 1, 10);
    HAL_SPI_Transmit(&hspi1, data, len, 10);
    HAL_GPIO_WritePin(BMI323_CS_PORT, BMI323_CS_PIN, GPIO_PIN_SET);
}

static void BMI323_SPI_Read(uint8_t reg, uint8_t *data, uint16_t len) {
    uint8_t tx_reg = reg | 0x80; // Bit 7 = 1 để Đọc
    uint8_t dummy = 0x00;

    HAL_GPIO_WritePin(BMI323_CS_PORT, BMI323_CS_PIN, GPIO_PIN_RESET);
    HAL_SPI_Transmit(&hspi1, &tx_reg, 1, 10);

    // Đọc Dummy Byte (Bắt buộc với cảm biến Bosch trên SPI)
    HAL_SPI_Receive(&hspi1, &dummy, 1, 10);

    HAL_SPI_Receive(&hspi1, data, len, HAL_MAX_DELAY);
    HAL_GPIO_WritePin(BMI323_CS_PORT, BMI323_CS_PIN, GPIO_PIN_SET);
}

// =====================================================================
// CÁC HÀM XỬ LÝ CHÍNH
// =====================================================================
void IMU_Init(void) {
    uint8_t id_data[2] = {0};

    // 1. Chờ cảm biến lên nguồn
    HAL_Delay(100);

    // 2. Ép cảm biến chuyển từ I2C sang SPI mode (Gửi 1 xung giả vào chân CS)
    HAL_GPIO_WritePin(BMI323_CS_PORT, BMI323_CS_PIN, GPIO_PIN_SET);
    HAL_Delay(1);
    HAL_GPIO_WritePin(BMI323_CS_PORT, BMI323_CS_PIN, GPIO_PIN_RESET);
    HAL_Delay(1);
    HAL_GPIO_WritePin(BMI323_CS_PORT, BMI323_CS_PIN, GPIO_PIN_SET);
    HAL_Delay(10);

    // 3. Đọc ID để kiểm tra kết nối
    for(int retry = 0; retry < 5; retry++) {
        BMI323_SPI_Read(BMI323_REG_CHIP_ID, id_data, 2);
        bmi323_chip_id = id_data[0];

        if (bmi323_chip_id == 0x43) break;
        HAL_Delay(50);
    }

    // 4. Cấu hình cảm biến nếu nhận diện đúng Chip ID
    if (bmi323_chip_id == 0x43) {
        // Bật Accel (Gửi LSB, MSB)
        uint8_t acc_cfg[2] = {0x08, 0x70};
        BMI323_SPI_Write(BMI323_REG_ACC_CONF, acc_cfg, 2);

        // Bật Gyro (Gửi LSB, MSB)
        uint8_t gyr_cfg[2] = {0x08, 0x70};
        BMI323_SPI_Write(BMI323_REG_GYR_CONF, gyr_cfg, 2);

        HAL_Delay(50); // Chờ cấu hình áp dụng thành công
    }
}

void IMU_Read_Data(void) {
    if (bmi323_chip_id != 0x43) return; // Nếu cảm biến lỗi thì không đọc

    uint8_t raw_data[12];

    // Đọc một mạch 12 byte từ thanh ghi ACC_X (0x03)
    BMI323_SPI_Read(BMI323_REG_ACC_X, raw_data, 12);

    // 1. Ghép 2 byte lại để lấy giá trị Raw (int16_t)
    acc_raw[0] = (int16_t)((raw_data[1] << 8)  | raw_data[0]);
    acc_raw[1] = (int16_t)((raw_data[3] << 8)  | raw_data[2]);
    acc_raw[2] = (int16_t)((raw_data[5] << 8)  | raw_data[4]);

    gyr_raw[0] = (int16_t)((raw_data[7] << 8)  | raw_data[6]);
    gyr_raw[1] = (int16_t)((raw_data[9] << 8)  | raw_data[8]);
    gyr_raw[2] = (int16_t)((raw_data[11] << 8) | raw_data[10]);

    // 2. Chuyển đổi sang đơn vị thực tế (Dựa vào dải đo mặc định của BMI323)
    // Gia tốc chia 16384 (dải +-2g) | Gyro chia 262.4 (dải +-125 dps)
    ax_g = acc_raw[0] / 16384.0f;
    ay_g = acc_raw[1] / 16384.0f;
    az_g = acc_raw[2] / 16384.0f;

    gx_dps = gyr_raw[0] / 262.4f;
    gy_dps = gyr_raw[1] / 262.4f;
    gz_dps = gyr_raw[2] / 262.4f;
}
